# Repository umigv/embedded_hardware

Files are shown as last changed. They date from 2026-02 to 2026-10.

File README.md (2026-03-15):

# UMARV Hardware

PCB designs and hardware files for the University of Michigan Autonomous Robotic Vehicle (UMARV) project.

> **For CS/software folks:** You probably just need to browse a schematic or check a pinout. Jump to the folder for your board below and open the `README.md` inside it — no Git setup needed, GitHub renders schematics and PDFs in the browser.

---

## Repo Structure

```
embedded_hardware/
├── estop-lora-esp32/        # Remote E-stop board (LoRa + ESP32)
│   ├── schematic.SchDoc
│   ├── board.PcbDoc
│   ├── Project Outputs/     #includes Gerber(.GM, .GBL, etc), DRC, Pick and Place files
│   └── README.md            # Pinout, ROS2 topic links, revision history
├── power-distribution/
├── motor-driver/
├── coming-soon/
├── .gitignore
└── README.md                # (this file)
```

Each board folder should have its own `README.md` explaining or linking to: 
- What the board does
- Which ROS2 topics / signals it connects to
- Connector pinout

---

## First-Time Setup (Hardware Contributors)

You need to be a member of the `umigv` GitHub org first. 

### Clone only your board (recommended — avoids downloading large files from other boards)

```bash
git clone --no-checkout https://github.com/umigv/embedded_hardware
cd hardware
git sparse-checkout init --cone
git sparse-checkout set your-board-folder-name
git checkout main
```

Replace `your-board-folder-name` with the actual folder, e.g. `estop-lora-esp32`.
- Naming convention: `function-component`

### Clone everything

```bash
git clone https://github.com/umigv/hardware
cd hardware
```

---

## Pushing a New Board

### 1. If you cloned with sparse checkout, add your folder to the sparse list first

```bash
git sparse-checkout add your-new-board-name
```

### 2. Create your folder and add files

```bash
mkdir your-new-board-name
cd your-new-board-name
# Copy your Altium files in here
```

### 3. Commit and push

```bash
git add your-new-board-name/
git commit -m "your-new-board-name: initial upload rev1"
git push
```

---
## Adding a New Board from an Existing Repo

If your board was previously its own git repository, delete the nested 
`.git` folder before adding it here — otherwise git will treat it as a 
submodule instead of tracking your files.

**Windows:**
```powershell
Remove-Item -Recurse -Force your-board-folder/.git
```
**Mac/Linux:**
```bash
rm -rf your-board-folder/.git
```
Your Altium files are unaffected — only the old repo history is removed, 
which lives on your personal GitHub anyway.

---

## Altium-Specific Notes

- check root .gitignore file for what it ignores
- individual folder .gitignores can be set to more specific, but cannot include what the root ignores 

- **Include:** `.SchDoc`, `.PcbDoc`, `.PrjPcb`, `gerbers/`, BOM export, project-specific libraries
- **Do not include:** `History/`, `__Previews/`, `ProjectLogs/` — these are auto-generated and handled by `.gitignore`
- If you use a shared library, document the library name and version in your board's `README.md` so others can open it cleanly

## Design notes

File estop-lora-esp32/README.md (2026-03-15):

# ARV E-Stop Transmitter PCB
**University of Michigan — ARV Project Team**  
Custom 2-layer PCB for wireless emergency stop (E-Stop) transmitter

---

## Overview

This board implements a handheld wireless E-Stop transmitter for the ARV autonomous robot platform. It interfaces an ESP32 microcontroller with a 900MHz LoRa radio module to transmit an emergency stop signal over >100m range. A switch triggers the E-Stop event, and an LED provides visual status feedback.
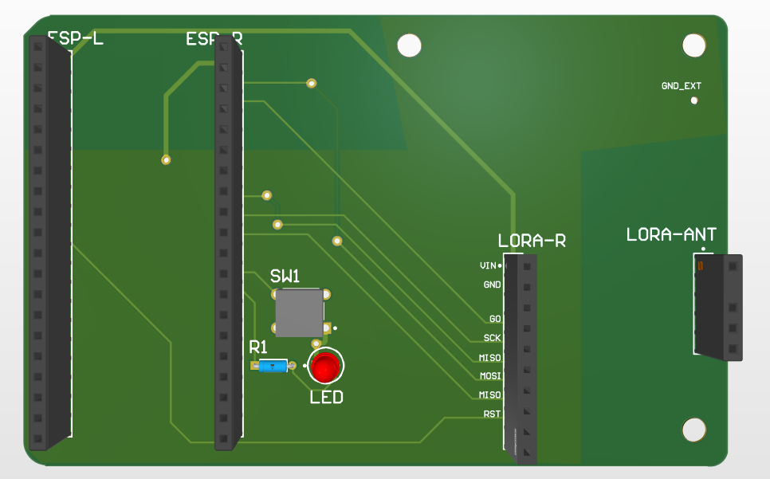
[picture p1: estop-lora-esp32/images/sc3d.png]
PCB 3D View

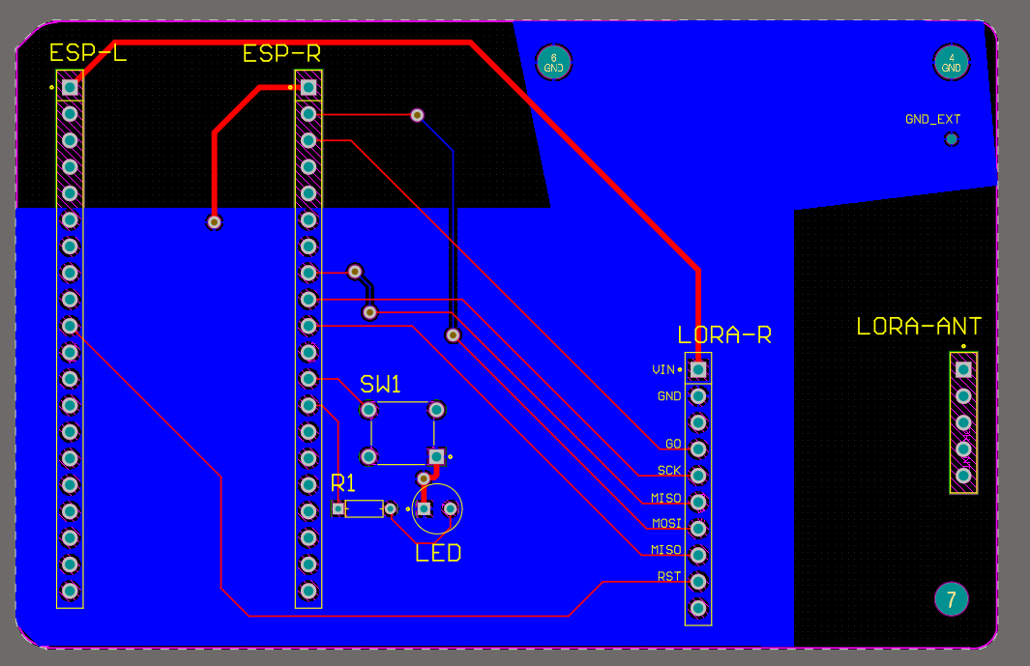
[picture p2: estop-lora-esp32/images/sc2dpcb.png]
PCB 2D View


---

## Software

### ROS2 Interface
Connected to `embedded_ros_marvin` via serial bridge.

ESP32 → UART serial → serial monitor script → `/tmp/estop_value.txt` → ROS2 `/estop` topic
- **Code** placed in: 

## Hardware

### Why These Parts
- **LoRa (SX1276):** 900MHz, >1km range, low power — chosen over
  WiFi/BT for reliability in outdoor competition environments
- **ESP32:** handles LoRa SPI + ROS2 serial bridge in one package,
  onboard WiFi useful for debugging

| Component | Part | Description |
|---|---|---|
| Microcontroller | ESP32 (via pin headers) | Main controller, SPI master |
| LoRa Radio | Adafruit RFM9x Breakout | 900MHz LoRa transceiver |
| Antenna | TI 915MHz (TI.92.2113) | Omnidirectional 915MHz antenna via SMA |
| Switch | Omron B3F-1000 | Tactile E-Stop trigger |
| Status LED | 3mm LED | Visual power/status indicator |
| Current Limiting Resistor | 220Ω metal film | LED current limiting |
| PCB | 2-layer FR4, 1.6mm, (Top signal + Bottom GND plane) | JLCPCB fabrication |

---
## Mechanical

- All mounting holes: #4-40, 3.175mm diameter.
- See `Project Outputs/fab-drawing.pdf` for dimensioned drawing.
---

## Pin Mapping

### ESP32 → LORA-R (RFM9x)

| ESP32 Pin | LoRa Pin | Function |
|---|---|---|
| GPIO (SCK) | SCK | SPI Clock |
| GPIO (MISO) | MISO | SPI Data In |
| GPIO (MOSI) | MOSI | SPI Data Out |
| GPIO (CS) | CS | Chip Select |
| GPIO | RST | Reset |
| GPIO | G0 | DIO0 / Interrupt |
| 3.3V | VIN | Power |
| GND | GND | Ground |

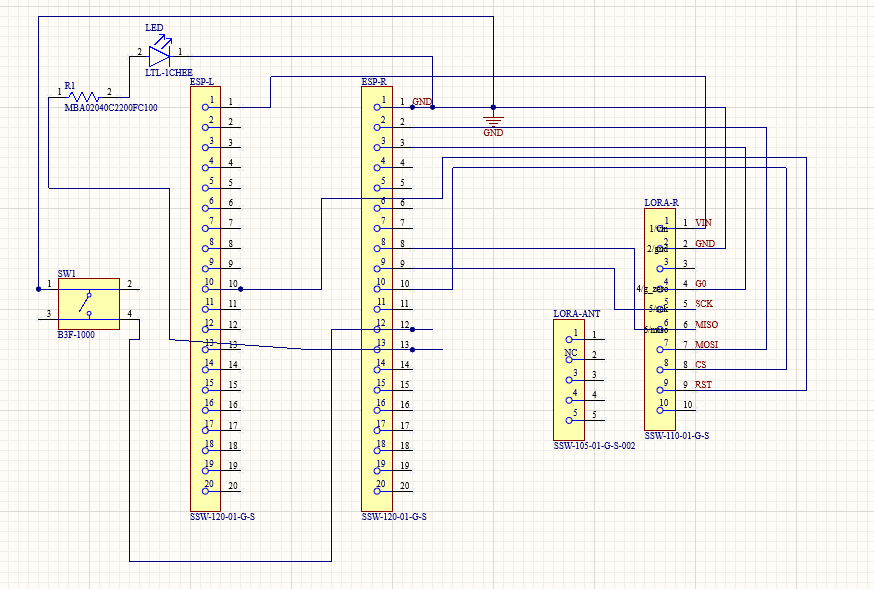
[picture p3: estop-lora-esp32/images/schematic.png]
PCB Schematic View


---

## Design Considerations

**RF / Antenna**
- Antenna operates at 915MHz (LoRa band)
- Copper keepout zone maintained around antenna radiating element to minimize ground plane interference
- SMA connector directly interfaces Adafruit RFM9x breakout to TI.92.2113 antenna — no impedance matching network required due to short connection length
- Adafruit breakout handles internal RF routing and matching to the RFM9x module

**Power**
- Board powered via ESP32 3.3V rail
- LoRa module powered from same 3.3V supply through VIN pin
- No dedicated power regulation on this PCB — relies on ESP32 dev board onboard regulator

**Ground Plane**
- Solid ground pour on bottom layer for signal integrity and noise reduction
- Thermal reliefs on GND through-hole pads for solderability
- Ground plane intentionally removed in antenna keepout region

**LED Circuit**
- GPIO → 220Ω (R1) → LED anode → LED cathode → GND
- At 3.3V supply with 2.0V LED forward voltage: $I = \frac{3.3-2.0}{220} \approx 5.9\text{mA}$
- Within safe operating range for standard 3mm LED (20mA max)

---

## Expected Performance

| Metric | Expected Value |
|---|---|
| Operating Frequency | 915 MHz |
| Modulation | LoRa (chirp spread spectrum) |
| Typical Range (open field) | 300m – 1km depending on spreading factor |
| Supply Voltage | 3.3V |
| LED Current | ~6mA |
| Board Dimensions | See PCB files |

> **Note:** Actual range dependent on firmware spreading factor, transmit power settings, and environment. LoRa range degrades significantly in urban/indoor environments with multipath interference.

---

## Repository Structure

```
arv-e_stop-pcb/
├── transmitter.SchDoc        # Altium schematic
├── transmitter.PcbDoc        # Altium PCB layout
├── lora_transmitter.PrjPcb   # Altium project file
├── Project Outputs/          # Generated Gerber + drill files
│   ├── Gerber/
│   └── NC Drill/
└── README.md
```

---

## Known Limitations & Future Work

- No onboard power regulation — dependent on ESP32 dev board
- No hardware debounce on SW1 — must be handled in firmware
- Keepout zone is smaller than theoretical λ/4 at 915MHz (~82mm) due to board size constraints

---

## Credits

- **ARV Project Team — University of Michigan**
- Contributors :  [@yourusername](https://github.com/yourusername)
- Developed: September 2025 - March 2026
- Last Modified: March 14, 2026

---

## License

MIT license for redistribution.

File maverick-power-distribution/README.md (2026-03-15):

# PowerDistributionBoard

see https://docs.google.com/document/d/1kiOH-C_xCofk4zljN7bb7FMuJ3Gous0_wGufArYLE6A/edit?tab=t.0

## Description 

PCB that will function as the power distribution for Maverick, namely for the motor controllers present on the robot. The motors and their respective motor controllers are drawing the most power on the robot so it is important to distribute power to them in a safe and controlled way.

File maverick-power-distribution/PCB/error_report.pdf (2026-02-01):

Change Order Report For Project | MaverickPowerDistribution_v1.0.PrjPcb And MaverickPowerDistribution_v1.0.PrjPcb
Action Object | Change Document | Status

Add Components
Add | D1 - LED_blownA | To PCB1.PcbDoc
Add | D1 - LED_blownB | To PCB1.PcbDoc
Add | LED1 | To PCB1.PcbDoc
Add | LED2 | To PCB1.PcbDoc
Add | U3 | To PCB1.PcbDoc

Add Pins To Nets
Add | C24-1 to NetC24_1 | Unknown Pin: Pin C24-1 In PCB1.PcbDoc
Add | C24-2 to 4.6V | Unknown Pin: Pin C24-2 In PCB1.PcbDoc
Add | C25-1 to GND | Unknown Pin: Pin C25-1 In PCB1.PcbDoc
Add | C25-2 to 4.6V | Unknown Pin: Pin C25-2 In PCB1.PcbDoc
Add | D1 - LED_blownA-1 to NetD1 - | In PCB1.PcbDoc
| LED_blownA_1 | | Unknown Pin: Pin D1 - LED_blownA-1
Add | D1 - LED_blownA-2 to GND | In PCB1.PcbDoc | Unknown Pin: Pin D1 - LED_blownA-2
Add | D1 - LED_blownB-1 to NetD1 - | In PCB1.PcbDoc
| LED_blownB_1 | | Unknown Pin: Pin D1 - LED_blownB-1
Add | D1 - LED_blownB-2 to GND | In PCB1.PcbDoc | Unknown Pin: Pin D1 - LED_blownB-2
Add | LED1-1 to NetLED1_1 | Unknown Pin: Pin LED1-1 In PCB1.PcbDoc
Add | LED1-2 to GND | Unknown Pin: Pin LED1-2 In PCB1.PcbDoc
Add | LED2-1 to NetLED2_1 | Unknown Pin: Pin LED2-1 In PCB1.PcbDoc
Add | LED2-2 to GND | Unknown Pin: Pin LED2-2 In PCB1.PcbDoc
Add | U3-1 to GND | Unknown Pin: Pin U3-1 In PCB1.PcbDoc
Add | U3-2 to NetC23_2 | Unknown Pin: Pin U3-2 In PCB1.PcbDoc
Add | U3-3 to 26V | Unknown Pin: Pin U3-3 In PCB1.PcbDoc
Add | U3-4 to NetC24_1 | Unknown Pin: Pin U3-4 In PCB1.PcbDoc
Add | U3-6 to NetC23_1 | Unknown Pin: Pin U3-6 In PCB1.PcbDoc

Add Component Class Members
Add | C24 to Buck + LDO | In PCB1.PcbDoc | Failed to add class member : Component C24 Capacitor
Add | C25 to Buck + LDO | In PCB1.PcbDoc | Failed to add class member : Component C25 Capacitor
Add | D1 - LED_blownA to F1 | In PCB1.PcbDoc | Failed to add class member : Component D1 - LED_blownA (D1 - LED_blown) AP2012EC
Add | D1 - LED_blownB to F2 | In PCB1.PcbDoc | Failed to add class member : Component D1 - LED_blownB (D1 - LED_blown) AP2012EC
Add | LED1 to MCU | In PCB1.PcbDoc | Failed to add class member : Component LED1 AP2012EC
Add | LED2 to MCU | In PCB1.PcbDoc | Failed to add class member : Component LED2 AP2012EC
Add | U3 to Buck + LDO | In PCB1.PcbDoc | Failed to add class member : Component U3 TPS54202DDCR
Sunday 1-Feb-01/2026 4:12:28 PM | Page 1 of 1

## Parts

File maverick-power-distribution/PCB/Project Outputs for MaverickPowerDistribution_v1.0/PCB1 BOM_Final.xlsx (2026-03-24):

Comment | Description | Designator | Footprint | LibRef | Quantity
Button | Button | B_OLED1, B_RST1 | TS1187ABAB | C318884 | 2
GZ1608D601TF | Ferrite Bead | BEAD1 | BEADC1608X95N | GZ1608D601TF | 1
KT-0603R | Red 0603 Light Emitting Diodes | BLOWN_LEDA, BLOWN_LEDB | LED_KT-0603R | KT-0603R | 2
CL05B103KB5NNNC | Capacitor, Ceramic (MLCC), 10nF, ±10%, 50V, X7R, ±10%, SMD 0402 | C1, C4, C8 | CAP-0402 | CL05B103KB5NNNC | 3
CL05B104KB54PNC | Capacitor, Ceramic (MLCC), 100nF, ±10%, 50V, X7R, ±10%, SMD 0402 | C2 | CAP-0402 | CL05B104KB54PNC | 1
CL05A105KA5NQNC | Capacitor, Ceramic (MLCC), 1uF, ±10%, 25V, X5R, ±10%, SMD 0402 | C3 | CAP-0402 | CL05A105KA5NQNC | 1
CL05A475MP5NRNC | Capacitor, Ceramic (MLCC), 4.7uF, ±20%, 10V, X5R, ±20%, SMD 0402 | C5 | CAP-0402 | CL05A475MP5NRNC | 1
CL05B104KO5NNNC | Capacitor, Ceramic (MLCC), 100nF, ±10%, 16V, X7R, ±10%, SMD 0402 | C6, C18 | CAPC1005X60N | CL05B104KO5NNNC | 2
CL05B104KO5NNNC | Capacitor, Ceramic (MLCC), 100nF, ±10%, 16V, X7R, ±10%, SMD 0402 | C7, C23 | CAP-0402 | CL05B104KO5NNNC | 2
CC0805KRX7R9BB104 | Capacitor, Ceramic (MLCC), 100nF, ±10%, 50V, X7R, ±10%, SMD 0805 | C9A, C9B | CAP-0805 | CC0805KRX7R9BB104 | 2
CL21B102KBCNNNC | Capacitor, Ceramic (MLCC), 1nF, ±10%, 50V, X7R, ±10%, SMD 0805 | C10A, C10B | CAP-0805 | CL21B102KBCNNNC | 2
CL05A225MQ5NSNC | Capacitor, Ceramic (MLCC), 2.2uF, ±20%, 6.3V, X5R, ±20%, SMD 0402 | C16, C17 | CAP-0402 | CL05A225MQ5NSNC | 2
CL05A106MQ5NUNC | Capacitor, Ceramic (MLCC), 10uF, ±20%, 6.3V, X5R, ±20%, SMD 0402 | C19 | CAPC1005X60N | CL05A106MQ5NUNC | 1
CL05A106MQ5NUNC | Capacitor, Ceramic (MLCC), 10uF, ±20%, 6.3V, X5R, ±20%, SMD 0402 | C20, C21 | CAP-0402 | CL05A106MQ5NUNC | 2
CL21A476MQYNNNE | Capacitor, Ceramic (MLCC), 47uF, ±20%, 6.3V, X5R, ±20%, SMD 0805 | C25 | CAP-0805 | CL21A476MQYNNNE | 1
LTST-C190GKT |  | D_LED1, D_LED2 | LEDM1608X80 | LTST-C190GKT | 2
178.6165.0002 | FUSE HOLDER BLADE 80V PCB | Fuse1A, Fuse1B | FP-178_6165-MFG | CMP-08604-000022-1 | 2
43045-0201 | CONN HEADER R/A 2POS | J1_PWR, J_MTR1A, J_MTR1B | FP-43045-0201-MFG | CMP-04776-000998-1 | 3
FTSH-107-01-L-DV-K | CONN HEADER SMD 14POS 1.27MM | J2 | FP-FTSH-107-01-L-DV-K-MFG | CMP-02766-001412-1 | 1
AMS1117-3.3 | LDO Voltage Regulators 1A, 3.3V | LDO_1 | FP-AMS1117-IPC_C | CMP-209535-000001-1 | 1
TF-01A | Standard Card Edge Connectors | MICRO_SD1 | TF-01A | TF-01A | 1
SS8050 | BJT NPN | Q1A, Q1B | SOT-23-3_L2.9-W1.3-P1.90-LS2.4-BR | SS8050(RANGE:200-350)_C2150 | 2
0603WAF3003T5E | Resistor, 300kΩ, ±1%, 100mW, 75V, ±100ppm/℃, -55℃~+155℃, SMD 0603 | R1 | RESC1607X60N | 0603WAF3003T5E | 1
0603WAF5103T5E | Resistor, 510kΩ, ±1%, 100mW, 75V, ±100ppm/℃, -55℃~+155℃, SMD 0603 | R2 | RESC1607X60N | 0603WAF5103T5E | 1
0402WGF1003TCE | Resistor, 100kΩ, ±1%, 62.5mW, 50V, ±100ppm/℃, -55℃~+155℃, SMD 0402 | R3 | RES-0402 | 0402WGF1003TCE | 1
0402WGF1002TCE | Resistor, 10kΩ, ±1%, 62.5mW, 50V, ±100ppm/℃, -55℃~+155℃, SMD 0402 | R4, R5, R6, R7, R8, R9, R10, R11, R14 | RES-0402 | 0402WGF1002TCE | 9
0402WGF220JTCE | Resistor, 22Ω, ±1%, 62.5mW, 50V, ±200ppm/℃, -55℃~+155℃, SMD 0402 | R12, R13 | RES-0402 | 0402WGF220JTCE | 2
0402WGF1000TCE | Resistor, 100Ω, ±1%, 62.5mW, 50V, ±200ppm/℃, -55℃~+155℃, SMD 0402 | R15, R16 | RES-0402 | 0402WGF1000TCE | 2
390kΩ | 390k Resistor | R20 | R0402 | 0402WGF3903TCE | 1
RC0603FR-07100KL | 100 kOhms Â±1% 0.1W, 1/10W Chip Resistor 0603 (1608 Metric) Moisture Resistant Thick Film | R21 | RESC1607X60N | RC0603FR-07100KL | 1
0603WAF1302T5E | Resistor, 13kΩ, ±1%, 100mW, 75V, ±100ppm/℃, -55℃~+155℃, SMD 0603 | R22 | RESC1607X60N | C22793 | 1
0603WAF1002T5E | Resistor, 10kΩ, ±1%, 100mW, 75V, ±100ppm/℃, -55℃~+155℃, SMD 0603 | R_BaseA, R_BaseB | RESC1607X60N | 0603WAF1002T5E | 2
0402WGF1202TCE | Resistor, 12kΩ, ±1%, 62.5mW, 50V, ±100ppm/℃, -55℃~+155℃, SMD 0402 | R_BLOWN1A, R_BLOWN1B | RES-0402 | 0402WGF1202TCE | 2
STM32L412KBT6 | No Description Available | U1 | LQFP-32 | STM32L412KBT6 | 1
ACS711KEXLT-15AB-T | Current Sensor 15.5A 1 Channel Hall Effect, Open Loop Bidirectional 12-PowerWFQFN | U2A, U2B | XDCR_ACS711KEXLT-15AB-T | ACS711KEXLT-15AB-T | 2
TPS561201DDCT | 4.5V to 17V Input, 1A Synchronous Step-Down Voltage Regulator in 6-pin SOT-23 | U3 | SOT95P280X110-6N | TPS561201DDCT | 1
32.768kHz |  | X1 | OSC-SMD_4P-L3.2-W2.5-BL | SX3M32.768KM20F30TNN | 1

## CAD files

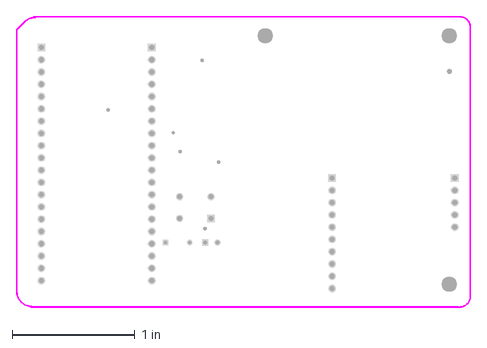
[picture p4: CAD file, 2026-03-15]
estop-lora-esp32/estop-lora-esp32 hole locations.DXF
3.71 x 2.38 in

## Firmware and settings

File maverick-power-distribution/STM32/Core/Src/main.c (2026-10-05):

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
/* Includes ------------------------------------------------------------------*/
#include "main.h"
#include "fatfs.h"

/* USER CODE BEGIN Includes */
#include <string.h>
#include <stdarg.h>
#include <stdio.h>
//#include "sdcard.h"
/* USER CODE END Includes */

I2C_HandleTypeDef hi2c1;

UART_HandleTypeDef hlpuart1;

SPI_HandleTypeDef hspi1;

/* USER CODE BEGIN PV */
char TxBuffer[250];
/* USER CODE END PV */

void SystemClock_Config(void);
static void MX_GPIO_Init(void);
static void MX_I2C1_Init(void);
static void MX_SPI1_Init(void);
static void MX_LPUART1_UART_Init(void);
/* USER CODE BEGIN 0 */

static void SD_Card_Test(void)
{
  FATFS FatFs;
  FIL Fil;
  FRESULT FR_Status;
  FATFS *FS_Ptr;
  UINT RWC, WWC; // Read/Write Word Counter
  DWORD FreeClusters;
  uint32_t TotalSize, FreeSpace;
  char RW_Buffer[200];
  do
  {
    //------------------[ Mount The SD Card ]--------------------
    FR_Status = f_mount(&FatFs, "", 1);
    if (FR_Status != FR_OK)
    {
      printf("Error! While Mounting SD Card, Error Code: (%i)\r\n", FR_Status);
      break;
    }
    printf("SD Card Mounted Successfully! \r\n\n");
//    UART_Print(TxBuffer);
    //------------------[ Get & Print The SD Card Size & Free Space ]--------------------
    f_getfree("", &FreeClusters, &FS_Ptr);
    TotalSize = (uint32_t)((FS_Ptr->n_fatent - 2) * FS_Ptr->csize * 0.5);
    FreeSpace = (uint32_t)(FreeClusters * FS_Ptr->csize * 0.5);
    printf("Total SD Card Size: %lu Bytes\r\n", TotalSize);
    printf("Free SD Card Space: %lu Bytes\r\n\n", FreeSpace);
//    UART_Print(TxBuffer);
    //------------------[ Open A Text File For Write & Write Data ]--------------------
    //Open the file
    FR_Status = f_open(&Fil, "TextFileWrite.txt", FA_WRITE | FA_READ | FA_CREATE_ALWAYS);
    if(FR_Status != FR_OK)
    {
      printf("Error! While Creating/Opening A New Text File, Error Code: (%i)\r\n", FR_Status);
//      UART_Print(TxBuffer);
      break;
    }
    printf("Text File Created & Opened! Writing Data To The Text File..\r\n\n");
    // (1) Write Data To The Text File [ Using f_puts() Function ]
    f_puts("Hello! From STM32 To SD Card Over SPI, Using f_puts()\n", &Fil);
    // (2) Write Data To The Text File [ Using f_write() Function ]
    strcpy(RW_Buffer, "Hello! From STM32 To SD Card Over SPI, Using f_write()\r\n");
    f_write(&Fil, RW_Buffer, strlen(RW_Buffer), &WWC);
    // Close The File
    f_close(&Fil);
    //------------------[ Open A Text File For Read & Read Its Data ]--------------------
    // Open The File
    FR_Status = f_open(&Fil, "TextFileWrite.txt", FA_READ);
    if(FR_Status != FR_OK)
    {
      printf("Error! While Opening (TextFileWrite.txt) File For Read.. \r\n");
      break;
    }
    // (1) Read The Text File's Data [ Using f_gets() Function ]
    f_gets(RW_Buffer, sizeof(RW_Buffer), &Fil);
    printf("Data Read From (TextFileWrite.txt) Using f_gets():%s", RW_Buffer);
    // (2) Read The Text File's Data [ Using f_read() Function ]
    f_read(&Fil, RW_Buffer, f_size(&Fil), &RWC);
    printf("Data Read From (TextFileWrite.txt) Using f_read():%s", RW_Buffer);
    // Close The File
    f_close(&Fil);
    printf(TxBuffer, "File Closed! \r\n\n");
    //------------------[ Open An Existing Text File, Update Its Content, Read It Back ]--------------------
    // (1) Open The Existing File For Write (Update)
    FR_Status = f_open(&Fil, "TextFileWrite.txt", FA_OPEN_EXISTING | FA_WRITE);
    FR_Status = f_lseek(&Fil, f_size(&Fil)); // Move The File Pointer To The EOF (End-Of-File)
    if(FR_Status != FR_OK)
    {
      printf("Error! While Opening (TextFileWrite.txt) File For Update.. \r\n");
      break;
    }
    // (2) Write New Line of Text Data To The File
    FR_Status = f_puts("This New Line Was Added During Update!\r\n", &Fil);
    f_close(&Fil);
    memset(RW_Buffer,'\0',sizeof(RW_Buffer)); // Clear The Buffer
    // (3) Read The Contents of The Text File After The Update
    FR_Status = f_open(&Fil, "TextFileWrite.txt", FA_READ); // Open The File For Read
    f_read(&Fil, RW_Buffer, f_size(&Fil), &RWC);
    printf("Data Read From (TextFileWrite.txt) After Update:%s", RW_Buffer);
    f_close(&Fil);
    //------------------[ Delete The Text File ]--------------------
    // Delete The File
    /*
    FR_Status = f_unlink(TextFileWrite.txt);
    if (FR_Status != FR_OK){
        sprintf(TxBuffer, "Error! While Deleting The (TextFileWrite.txt) File.. \r\n");
        UART_Print(TxBuffer);
    }
    */
  } while(0);
  //------------------[ Test Complete! Unmount The SD Card ]--------------------
  FR_Status = f_mount(NULL, "", 0);
  if (FR_Status != FR_OK)
  {
      printf("Error! While Un-mounting SD Card, Error Code: (%i)\r\n", FR_Status);
  } else{
      printf("SD Card Un-mounted Successfully! \r\n");
  }
}
//void UART_Printf(const char* fmt, ...) {
//    char buff[256];
//    va_list args;
//    va_start(args, fmt);
//    vsnprintf(buff, sizeof(buff), fmt, args);
//    HAL_UART_Transmit(&huart2, (uint8_t*)buff, strlen(buff), HAL_MAX_DELAY);
//    va_end(args);
//}
//
//void init() {
//    int code;
//    UART_Printf("Ready!\r\n");
//    //MX_SDIO_SD_Init();
//    code = SDCARD_Init(); //problems with this code
//    UART_Printf("Init code check\r\n");
//
//    FATFS fs;
//    FRESULT res = f_mount(&fs, "", 1);
//    if (res != FR_OK) {
//        UART_Printf("Mount failed: %d - ", res);
//        switch(res) {
//            case FR_NOT_READY:  UART_Printf("Card not ready/init failed\r\n"); break;
//            case FR_DISK_ERR:   UART_Printf("Hard disk error\r\n"); break;
//            case FR_NO_FILESYSTEM: UART_Printf("No valid FAT volume\r\n"); break;
//            default: UART_Printf("Unknown error\r\n");
//        }
//        return;
//    }
//    FIL fil;
//    const char* test_str = "SD card test data";
//    res = f_open(&fil, "test.txt", FA_CREATE_ALWAYS | FA_WRITE);
//    if (res == FR_OK) {
//        UINT bytes_written;
//        f_write(&fil, test_str, strlen(test_str), &bytes_written);
//        f_close(&fil);
//        UART_Printf("Wrote %d bytes to file\r\n", bytes_written);
//    }
//
//    //code = SDCARD_Init();
//
//    if(code < 0) {
//        UART_Printf("SDCARD_Init() failed: code = %d\r\n", code);
//        return;
//    }
//
//    UART_Printf("SDCARD_Init() done!\r\n");
//
//    uint32_t blocksNum;
//    code = SDCARD_GetBlocksNumber(&blocksNum);
//    if(code < 0) {
//        UART_Printf("SDCARD_GetBlocksNumber() failed: code = %d\r\n", code);
//        return;
//    }
//
//    UART_Printf("SDCARD_GetBlocksNumber() done! blocksNum = %u (or %u Mb)\r\n",
//        blocksNum, blocksNum/2000 /* same as * 512 / 1000 / 1000 */);
//
//    uint32_t startBlockAddr = 0x00ABCD;
//    uint32_t blockAddr = startBlockAddr;
//    uint8_t block[512];
//
//    snprintf((char*)block, sizeof(block), "0x%08X", (int)blockAddr);
//
//    code = SDCARD_WriteSingleBlock(blockAddr, block);
//    if(code < 0) {
//        UART_Printf("SDCARD_WriteSingleBlock() failed: code = %d\r\n", code);
//        return;
//    }
//    UART_Printf("SDCARD_WriteSingleBlock(0x%08X, ...) done!\r\n", blockAddr);
//
//    memset(block, 0, sizeof(block));
//
//    code = SDCARD_ReadSingleBlock(blockAddr, block);
//    if(code < 0) {
//        UART_Printf("SDCARD_ReadSingleBlock() failed: code = %d\r\n", code);
//        return;
//    }
//
//    UART_Printf("SDCARD_ReadSingleBlock(0x%08X, ...) done! block = \"%c%c%c%c%c%c%c%c%c%c...\"\r\n",
//        blockAddr, block[0], block[1], block[2], block[3], block[4], block[5], block[6], block[7], block[8], block[9]);
//
//    blockAddr = startBlockAddr + 1;
//    code = SDCARD_WriteBegin(blockAddr);
//    if(code < 0) {
//        UART_Printf("SDCARD_WriteBegin() failed: code = %d\r\n", code);
//        return;
//    }
//    UART_Printf("SDCARD_WriteBegin(0x%08X, ...) done!\r\n", blockAddr);
//
//    for(int i = 0; i < 3; i++) {
//        snprintf((char*)block, sizeof(block), "0x%08X", (int)blockAddr);
//
//        code = SDCARD_WriteData(block);
//        if(code < 0) {
//            UART_Printf("SDCARD_WriteData() failed: code = %d\r\n", code);
//            return;
//        }
//
//        UART_Printf("SDCARD_WriteData() done! blockAddr = %08X\r\n", blockAddr);
//        blockAddr++;
//    }
//
//    code = SDCARD_WriteEnd();
//    if(code < 0) {
//        UART_Printf("SDCARD_WriteEnd() failed: code = %d\r\n", code);
//        return;
//    }
//    UART_Printf("SDCARD_WriteEnd() done!\r\n");
//
//    blockAddr = startBlockAddr + 1;
//    code = SDCARD_ReadBegin(blockAddr);
//    if(code < 0) {
//        UART_Printf("SDCARD_ReadBegin() failed: code = %d\r\n", code);
//        return;
//    }
//    UART_Printf("SDCARD_ReadBegin(0x%08X, ...) done!\r\n", blockAddr);
//
//    for(int i = 0; i < 3; i++) {
//        code = SDCARD_ReadData(block);
//        if(code < 0) {
//            UART_Printf("SDCARD_ReadData() failed: code = %d\r\n", code);
//            return;
//        }
//
//        UART_Printf("SDCARD_ReadData() done! block = \"%c%c%c%c%c%c%c%c%c%c...\"\r\n",
//            block[0], block[1], block[2], block[3], block[4], block[5], block[6], block[7], block[8], block[9]);
//    }
//
//    code = SDCARD_ReadEnd();
//    if(code < 0) {
//        UART_Printf("SDCARD_ReadEnd() failed: code = %d\r\n", code);
//        return;
//    }
//    UART_Printf("SDCARD_ReadEnd() done!\r\n");
//}
//
//void loop() {
//    HAL_Delay(500);
//}
/* USER CODE END 0 */

/**
  * @brief  The application entry point.
  * @retval int
  */
int main(void)
{

  /* MCU Configuration--------------------------------------------------------*/

  /* Reset of all peripherals, Initializes the Flash interface and the Systick. */
  HAL_Init();

  /* Configure the system clock */
  SystemClock_Config();

  /* Initialize all configured peripherals */
  MX_GPIO_Init();
  MX_I2C1_Init();
  MX_SPI1_Init();
  MX_FATFS_Init();
  MX_LPUART1_UART_Init();
  /* USER CODE BEGIN 2 */
//  init();
//  HAL_Delay(100);
  SD_Card_Test();

  /* USER CODE END 2 */

  /* Infinite loop */
  /* USER CODE BEGIN WHILE */
  while (1)
  {
    /* USER CODE END WHILE */

    /* USER CODE BEGIN 3 */
  }
  /* USER CODE END 3 */
}

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
/* USER CODE BEGIN 4 */
#ifdef __GNUC__
#define PUTCHAR_PROTOTYPE int __io_putchar(int ch)
#else
  #define PUTCHAR_PROTOTYPE int fputc(int ch, FILE *f)
#endif /* __GNUC__ */
PUTCHAR_PROTOTYPE
{
  HAL_UART_Transmit(&hlpuart1, (uint8_t *)&ch, 1, 0xFFFF);
  return ch;
}
/* USER CODE END 4 */
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


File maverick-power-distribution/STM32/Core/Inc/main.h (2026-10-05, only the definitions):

#define SD_CS_Pin GPIO_PIN_4
#define SD_CS_GPIO_Port GPIOA
#define OSC_nEN_Pin GPIO_PIN_8
#define OSC_nEN_GPIO_Port GPIOA
#define TESTLED1_Pin GPIO_PIN_11
#define TESTLED1_GPIO_Port GPIOA
#define TESTLED2_Pin GPIO_PIN_12
#define TESTLED2_GPIO_Port GPIOA
#define SWDIO_Pin GPIO_PIN_13
#define SWDIO_GPIO_Port GPIOA
#define SWCLK_Pin GPIO_PIN_14
#define SWCLK_GPIO_Port GPIOA
#define VCP_RX_Pin GPIO_PIN_15
#define VCP_RX_GPIO_Port GPIOA
#define LD3_Pin GPIO_PIN_3
#define LD3_GPIO_Port GPIOB

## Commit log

2025-02-16 added subsheets
    [ADC.SchDoc, Display.SchDoc, Power.SchDoc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]
2025-02-23 added current sensing subsheet, and input power and pgnd
    [Current Sensing.SchDoc, MaverickPowerDistribution_v1.0.PrjPcb, PcbLib1.PcbLib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]
2025-03-16 added gitignore and slight improvments
    [Ammeter.SchDoc, Buck 3V3.SchDoc, MaverickPowerDistribution_v1.0.PrjPcb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]
2025-03-16 added missing files
    [MaverickPowerDistribution_v1.0.PrjPcb]
2025-03-16 changes to power sheet
    [Power.SchDoc]
2025-03-16 actually added
    [SD Card.SchDoc]
2025-03-16 actually actually
    [Ammeter.SchDoc, Buck 3V3.SchDoc, Display.SchDoc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]
2025-03-16 sd card
    [MaverickPowerDistribution_v1.0.PrjPcb, SD Card.SchDoc]
2025-03-16 added display
    [Ammeter.SchDoc, Buck 3V3.SchDoc, Display.SchDoc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]
2025-03-16 put pcb files into folder
    [ADC.SchDoc, Ammeter.SchDoc, Buck 3V3.SchDoc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]
2025-03-16 Added arduino code for auto zoom graph display
2025-03-17 refactor and small notes/changes
    [Display.SchDoc, MicroSD.SchDoc, N096-2864KSWEG01-H301_N096-2864KSWEG01-H30.SCHLIB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]
2025-03-17 added a bunch of comments for other contributors
    [Buck 3V3.SchDoc, Display.SchDoc, MicroSD.SchDoc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]
2025-03-17 proj file changed idk
    [MaverickPowerDistribution_v1.0.PrjPcb]
2025-03-17 added many comments and components
    [178P6165P0001.PcbLib, 178P6165P0001.SchLib, Buck 3V3.SchDoc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]
2025-03-17 added todo for molex connectors
    [Power.SchDoc]
2025-03-17 added base stm32 NUCLEO-L412KB project
2025-03-22 STM32: initialized peripherals except ADC
2025-03-23 PCB: added missing libs and small cleanups
    [ADC.SchDoc, Ammeter.SchDoc, MaverickPowerDistribution_v1.0.PrjPcb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]
2025-03-23 voltage follower stuff
    [Ammeter.SchDoc, MaverickPowerDistribution_v1.0.PrjPcb]
2025-03-23 PCB: added display schematic -sneha
    [Display.SchDoc]
2025-03-30 sd card driver
2025-03-30 Fuse indicator
    [Fuse.SchDoc, Power.SchDoc]
2025-04-05 updated main with new code, SDCard_Init() is now failing
    [PowerDistributionBoard.ioc, main.c, sdcard.c]
2025-04-06 STM32 2
    [MaverickPowerDistribution_v1.0.PrjPcb, STM32.SchDoc]
2025-04-07 lots of pcb stuff
    [Ammeter.SchDoc, Buck 3V3.SchDoc, Display.SchDoc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]
2025-04-07 display fixes
    [0402WGF3903TCE1_0402WGF3903TCE.SCHLIB, Display.SchDoc, MicroSD.SchDoc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]
2025-04-07 forgot to save idk altium is weird
    [Ammeter.SchDoc, Buck 3V3.SchDoc, Display.SchDoc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]
2025-04-08 updated ioc, added buck converter template, added LDO, added many component footprints, added display toggle, and more!
    [Ammeter.SchDoc, Buck 3V3.SchDoc, Display.SchDoc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]
2025-04-08 added reference to buck circuit
    [Regulator3V3.SchDoc]
2025-04-09 added some components to buck converter
    [Regulator3V3.SchDoc, STM32.SchDoc, SamacSys.PcbLib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]
2025-04-09 improved readability slightly
    [STM32.SchDoc]
2025-04-20 cleanup and added resistor and capacitor footprints
    [Ammeter.SchDoc, Display.SchDoc, Fuse.SchDoc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]
2025-10-26 - caps
    [Ammeter.SchDoc, Display.SchDoc, MicroSD.SchDoc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]
2025-10-26 - ammeter
    [Ammeter.SchDoc, MaverickPowerDistribution_v1.0.PrjPcb, SWD.SchDoc]
2025-11-14 joystick DMA
2025-11-14 Revert "joystick DMA"
    This reverts commit 328f4301445998900861046df2a9b5cec213e570.
2026-01-11 removed unloaded files
    [MaverickPowerDistribution_v1.0.PrjPcb, PCB1.PcbDoc]
2026-01-11 ammeter changes
    [Ammeter.SchDoc, PCB1.PcbDoc, Power.SchDoc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]
2026-01-13 new schematics
    [tps54202ddcr.PcbLib, tps54202ddcr.SchLib]
2026-01-27 test schematic
    [Regulator3V3.SchDoc]
2026-02-01 fixed missing components
    [Ammeter.SchDoc, Display.SchDoc, Fuse - 01.02.26 - 15.PcbLib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]
2026-02-02 rearranged layout
    [Ammeter.SchDoc, MaverickPowerDistribution_v1.0.PrjPcb, PCB1.PcbDoc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]
2026-02-02 rearranged layout2
    [MaverickPowerDistribution_v1.0.PrjPcb]
2026-02-08 Updated PCB
    [Ammeter.SchDoc, Power.SchDoc]
2026-02-08 Updated PCB II
    [Ammeter.SchDoc]
2026-02-08 new IP+ connection
    [Ammeter.SchDoc, Power.SchDoc]
2026-02-13 routing attempt
    [PCB1.PcbDoc, STM32.SchDoc]
2026-02-22 Revert "routing attempt"
    This reverts commit a1e6c72ef8f620de8409993d5c2dfec96918a05b.
    [PCB1.PcbDoc, STM32.SchDoc]
2026-03-12 new layout
    [Ammeter.SchDoc, Display.SchDoc, Fuse.SchDoc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]
2026-03-15 reorganize embedded_hardware
    [0402WGF3903TCE1_0402WGF3903TCE.SCHLIB, 178P6165P0001.PcbLib, 178P6165P0001.SchLib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]
2026-03-15 estop-lora-esp32: upload to shared repo
    uploading completed pcb of estop to hardware repo
    [ESP32_Dev_2018-4.sch, Pick Place for transmitter.csv, estop-lora-esp32 hole locations.DXF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]
2026-03-15 Update README with board addition instructions
2026-03-16 board shape
    [PCB1.PcbDoc]
2026-03-19 draft final board
    [PCB1.PcbDoc]
2026-03-21 added graphics & revised layout
    [PCB1.PcbDoc]
2026-03-23 final design power
    [Ammeter.SchDoc, Copy of PCB1.PcbDoc, Copy of Power.SchDoc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]
2026-03-24 final design v1.0
    [ACS711KEXLT-15AB-T.SchLib, ACS772-Hall_Effect_Sensor.PcbLib, ACS772-Hall_Effect_Sensor.SchLib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]
2026-03-24 BOM & Pick&Place
    [PCB1 BOM_Final.xlsx, PCB1_Pick&Place_Final.xlsx, Pick Place for PCB1.csv]
2026-10-05 updated pinout
    [PCB1.PcbDoc, Power.SchDoc, Regulator3V3.SchDoc]

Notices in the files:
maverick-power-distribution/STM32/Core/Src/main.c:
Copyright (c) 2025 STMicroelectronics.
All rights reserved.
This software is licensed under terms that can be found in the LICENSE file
